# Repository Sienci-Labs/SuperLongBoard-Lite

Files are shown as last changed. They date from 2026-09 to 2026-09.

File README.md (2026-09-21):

# SuperLongBoard Lite

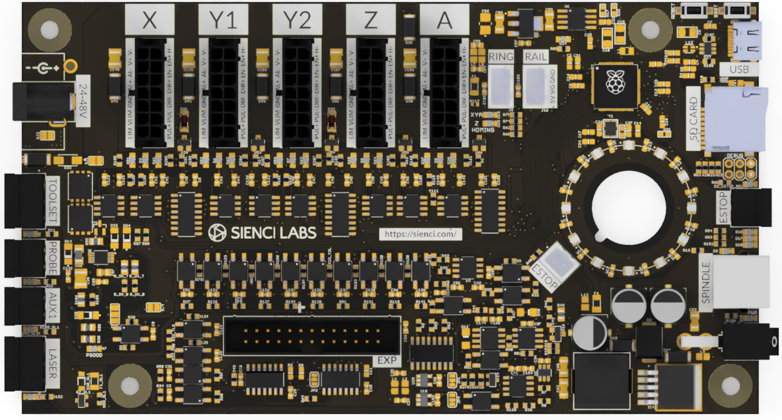
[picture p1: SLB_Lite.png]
SuperLongBoard Lite


The **SuperLongBoard Lite (SLB-Lite)** is Sienci Labs’ 24V CNC controller developed for the LongMill MK3, and other similar machines.

## Key Features

* grblHAL-based firmware
* Four-axis motion control
* Closed-loop stepper motor support
* USB connectivity
* SD card support
* Spindle/router and laser control
* Tool-length sensor support
* Auto-squaring
* Expansion interface
* UF2 firmware updates

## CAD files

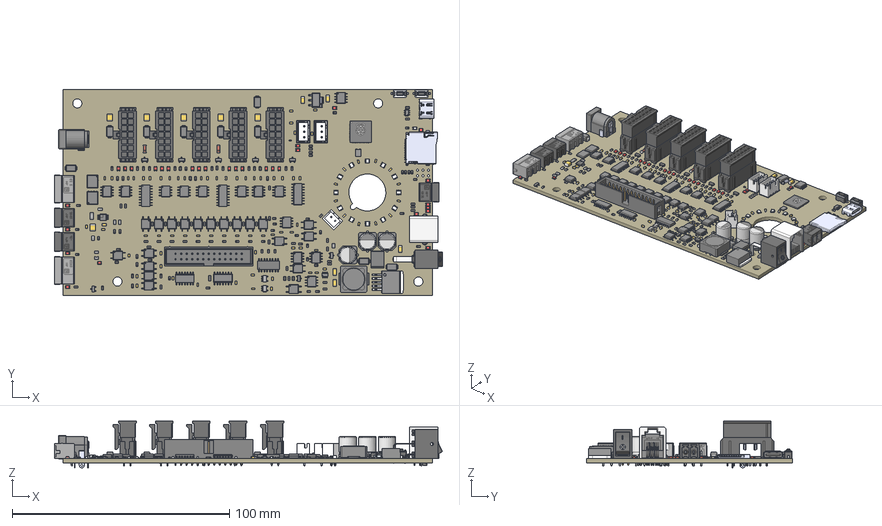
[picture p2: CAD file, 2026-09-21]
CAD/SuperLongboard-Lite 1.3.0.step
178.6 x 95.0 x 21.6 mm
Board
CAPMP3528X210N
SOT23-5 x 2
SOIC127P600X175-8N x 10
SOIC127P600X175-16N x 2
AMS1117-3.3
JST_B2B-XH-A_(LF)(SN)
SOD123FL
SOT95P240X120-3N x 5
QNMOS_PRPAK5X6_HUA x 2
SOIC-8
FIL_DLW21HN900SQ2L
OPTO_EL357N-G x 20
DIO_LL4148 x 4
MUB10A
SOT95P237X125-3N
SOT23
DIOM4325X250N
SOT95P280X145-6N
SOIC127P599X175-8N
USB-C-16P
SMT-JUMPER_3_1-NC_TRACE_SILK x 2
TACTILE_SWITCH_SMD_6.0X3.5MM x 2
MINIMELF x 2
LL-34 x 2
FB805 x 6
SJ x 3
0603-NO x 25
SOIC8_208MIL
SOT-23 x 2
1206L x 3
C0603K x 26
C0603 x 48
C0805
C1206 x 5
C1210 x 6
R0402
R0603 x 109
R1206
TF-PULL
QFN80
SMT-JUMPER_3_1-NC_TRACE_SILK (1)
MC1.5/2-G-3.81 x 3
PHOENIX_1803280 x 2
SOT95P280X145-6N (1)
SOIC127P600X175-14N
KH-PCB-6P6C
SOIC-16
KCD11-BL
JST_B3B-XH-A(LF)(SN) x 2
Components
CUI_DEVICES_MSD-1-A
B2B-XH-A(LF)(SN)
SOLID(5)^RJ11-TH_DS1133-S60BPX_RJ1_RJ11-TH_DS1133-S60BPX_PCB(2)_RJ11- TH_DS1133-S60BPX_PCB_1
Pin2
Pin1
Switch
Switch_IO_Surface
BodyPin1 x 2
DX07S016JA1R1500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

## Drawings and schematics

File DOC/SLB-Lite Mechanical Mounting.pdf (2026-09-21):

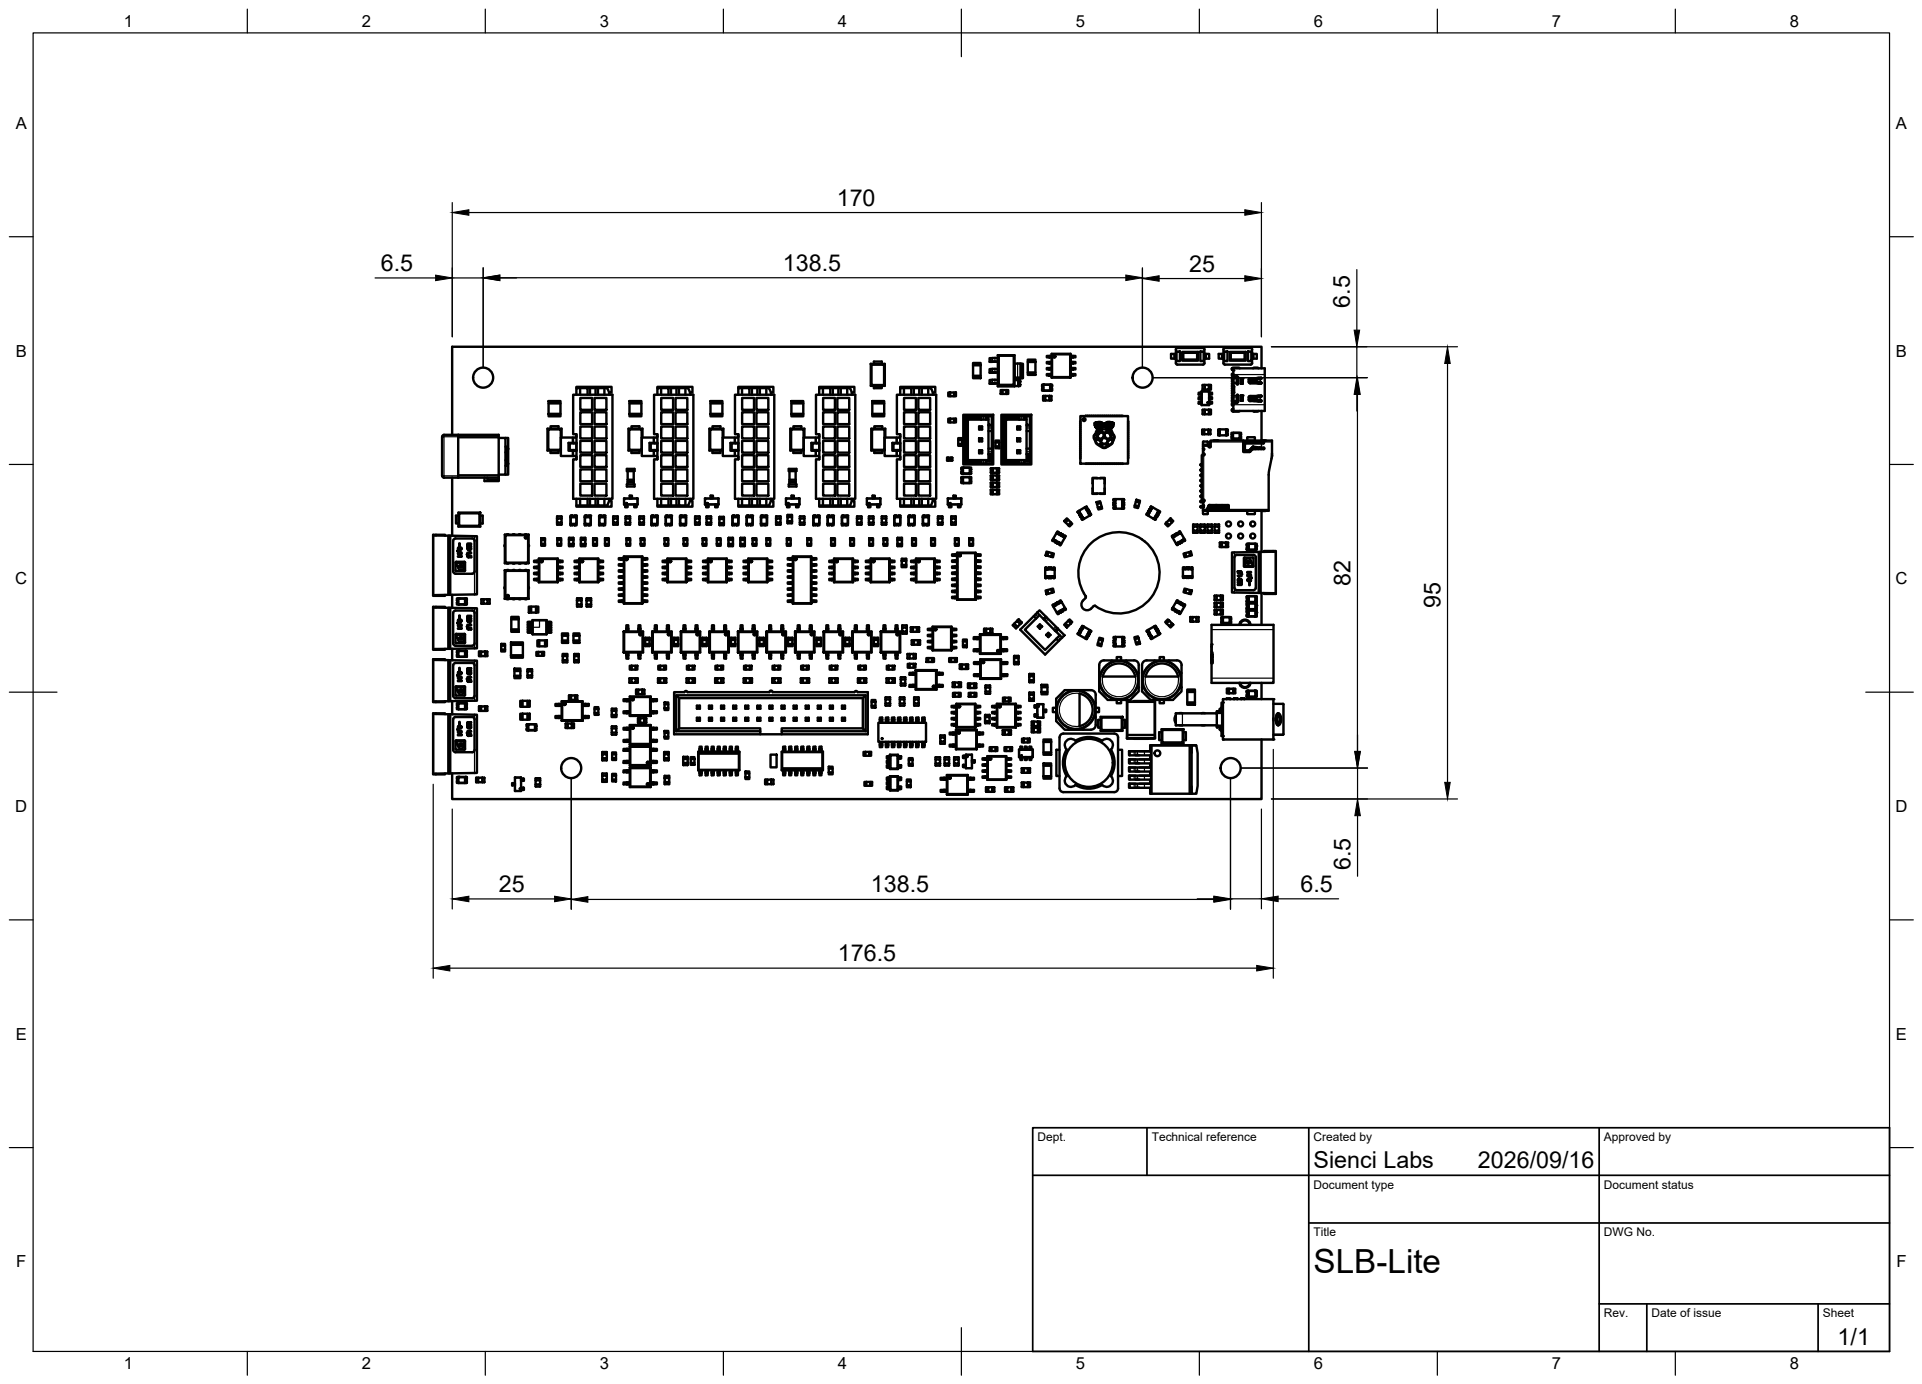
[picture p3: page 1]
Dept.; Technical reference; Created by; Approved by; Document type; Document status; Title; DWG No.; Rev.; Date of issue; Sheet; Sienci Labs

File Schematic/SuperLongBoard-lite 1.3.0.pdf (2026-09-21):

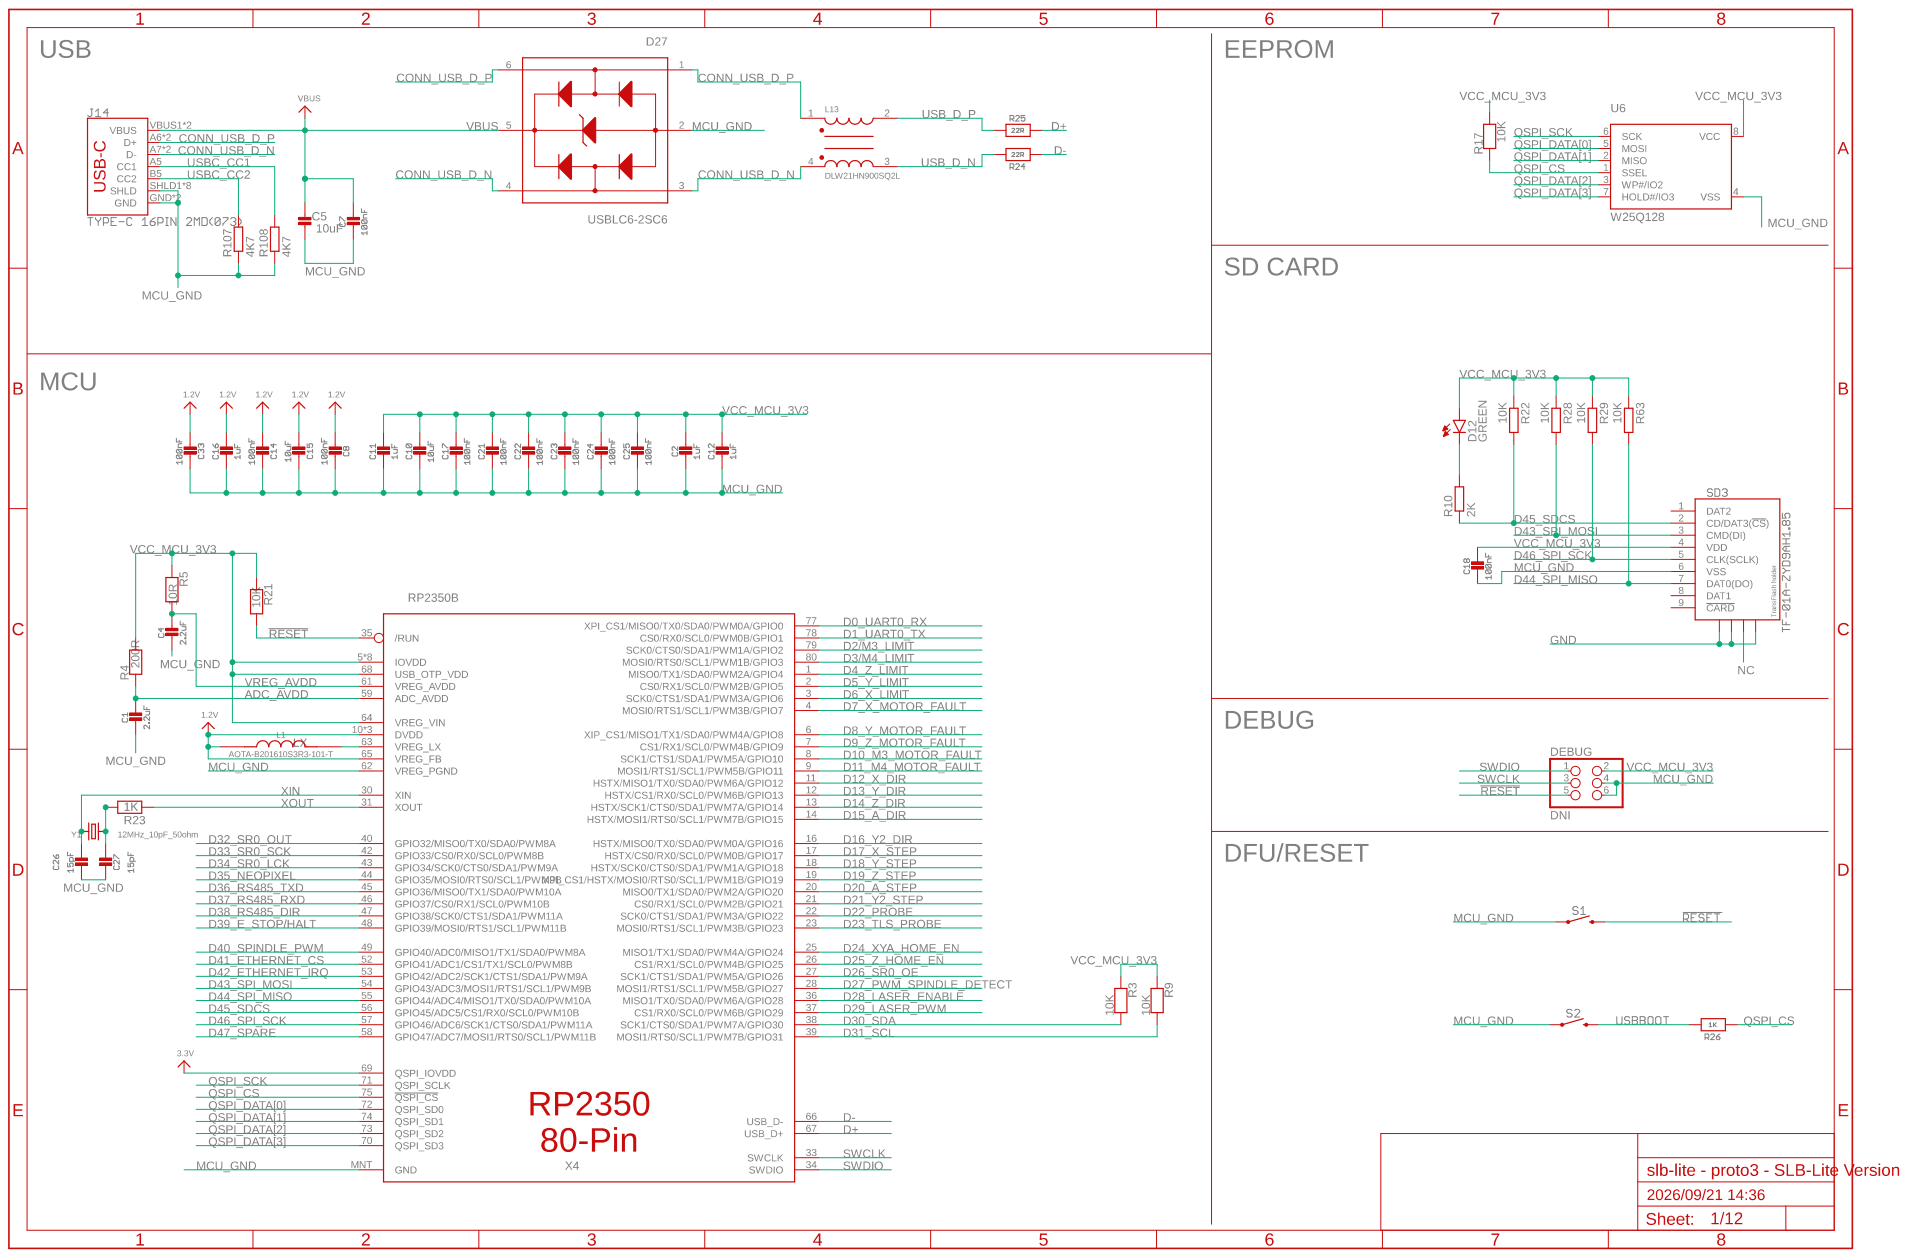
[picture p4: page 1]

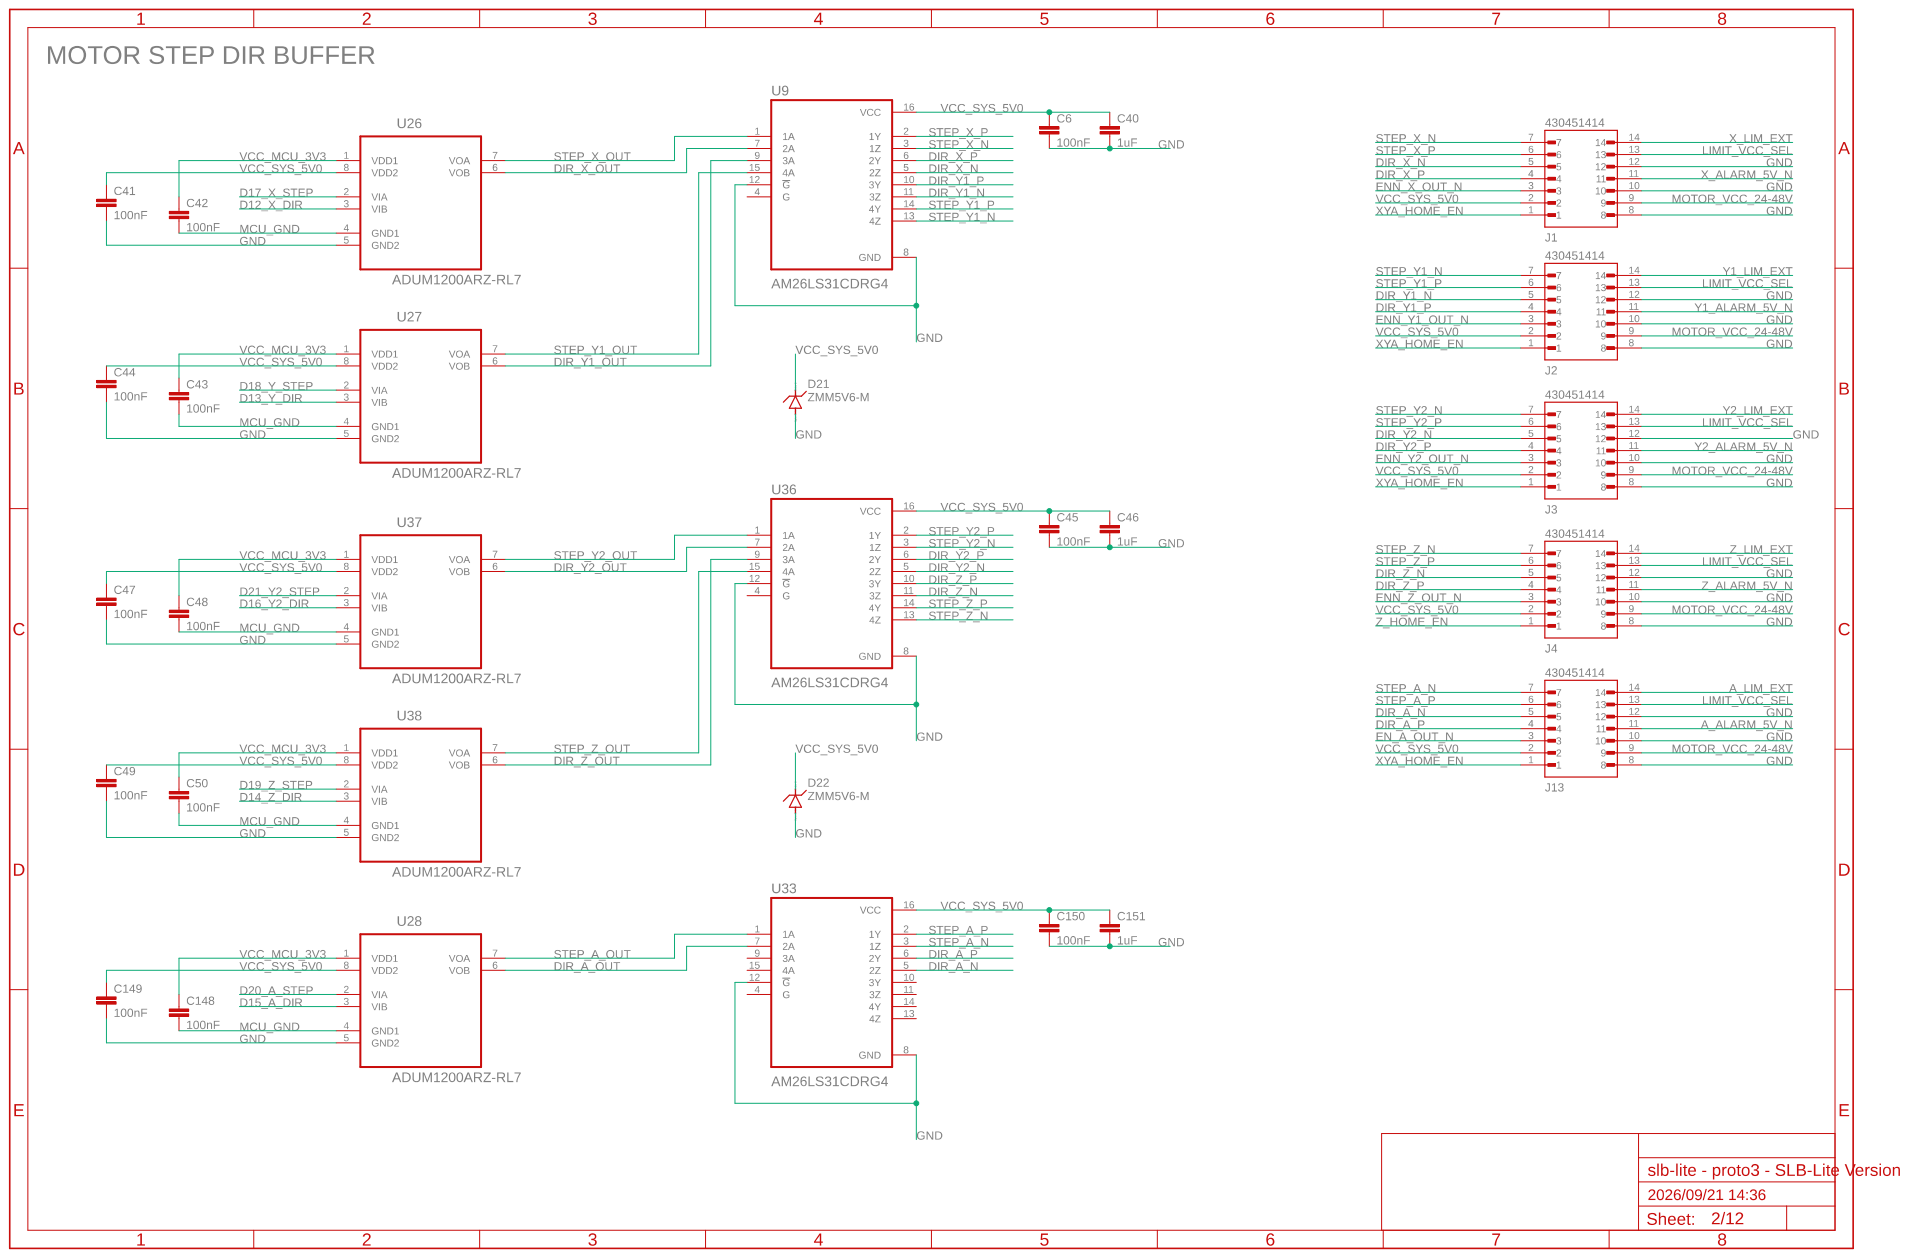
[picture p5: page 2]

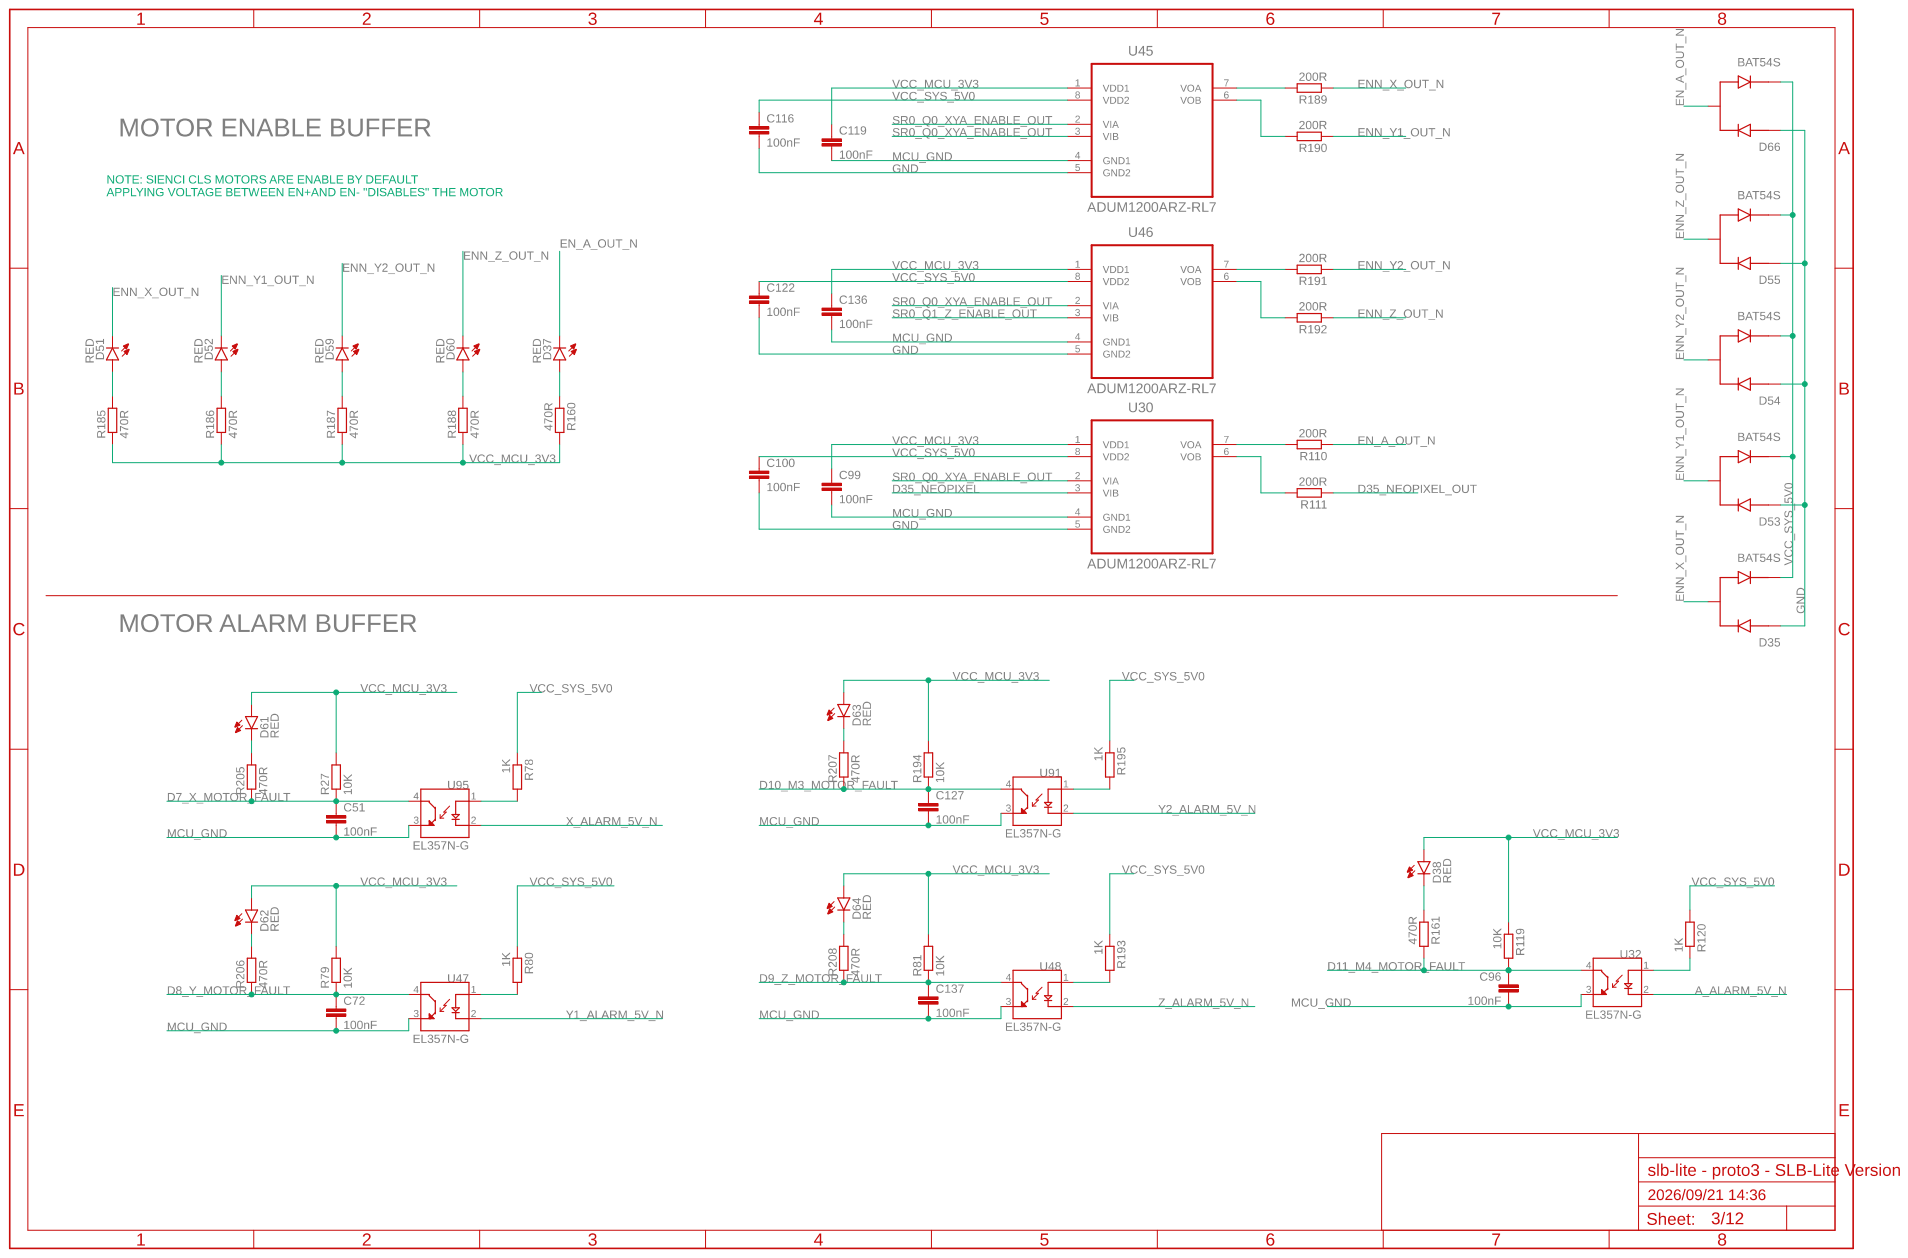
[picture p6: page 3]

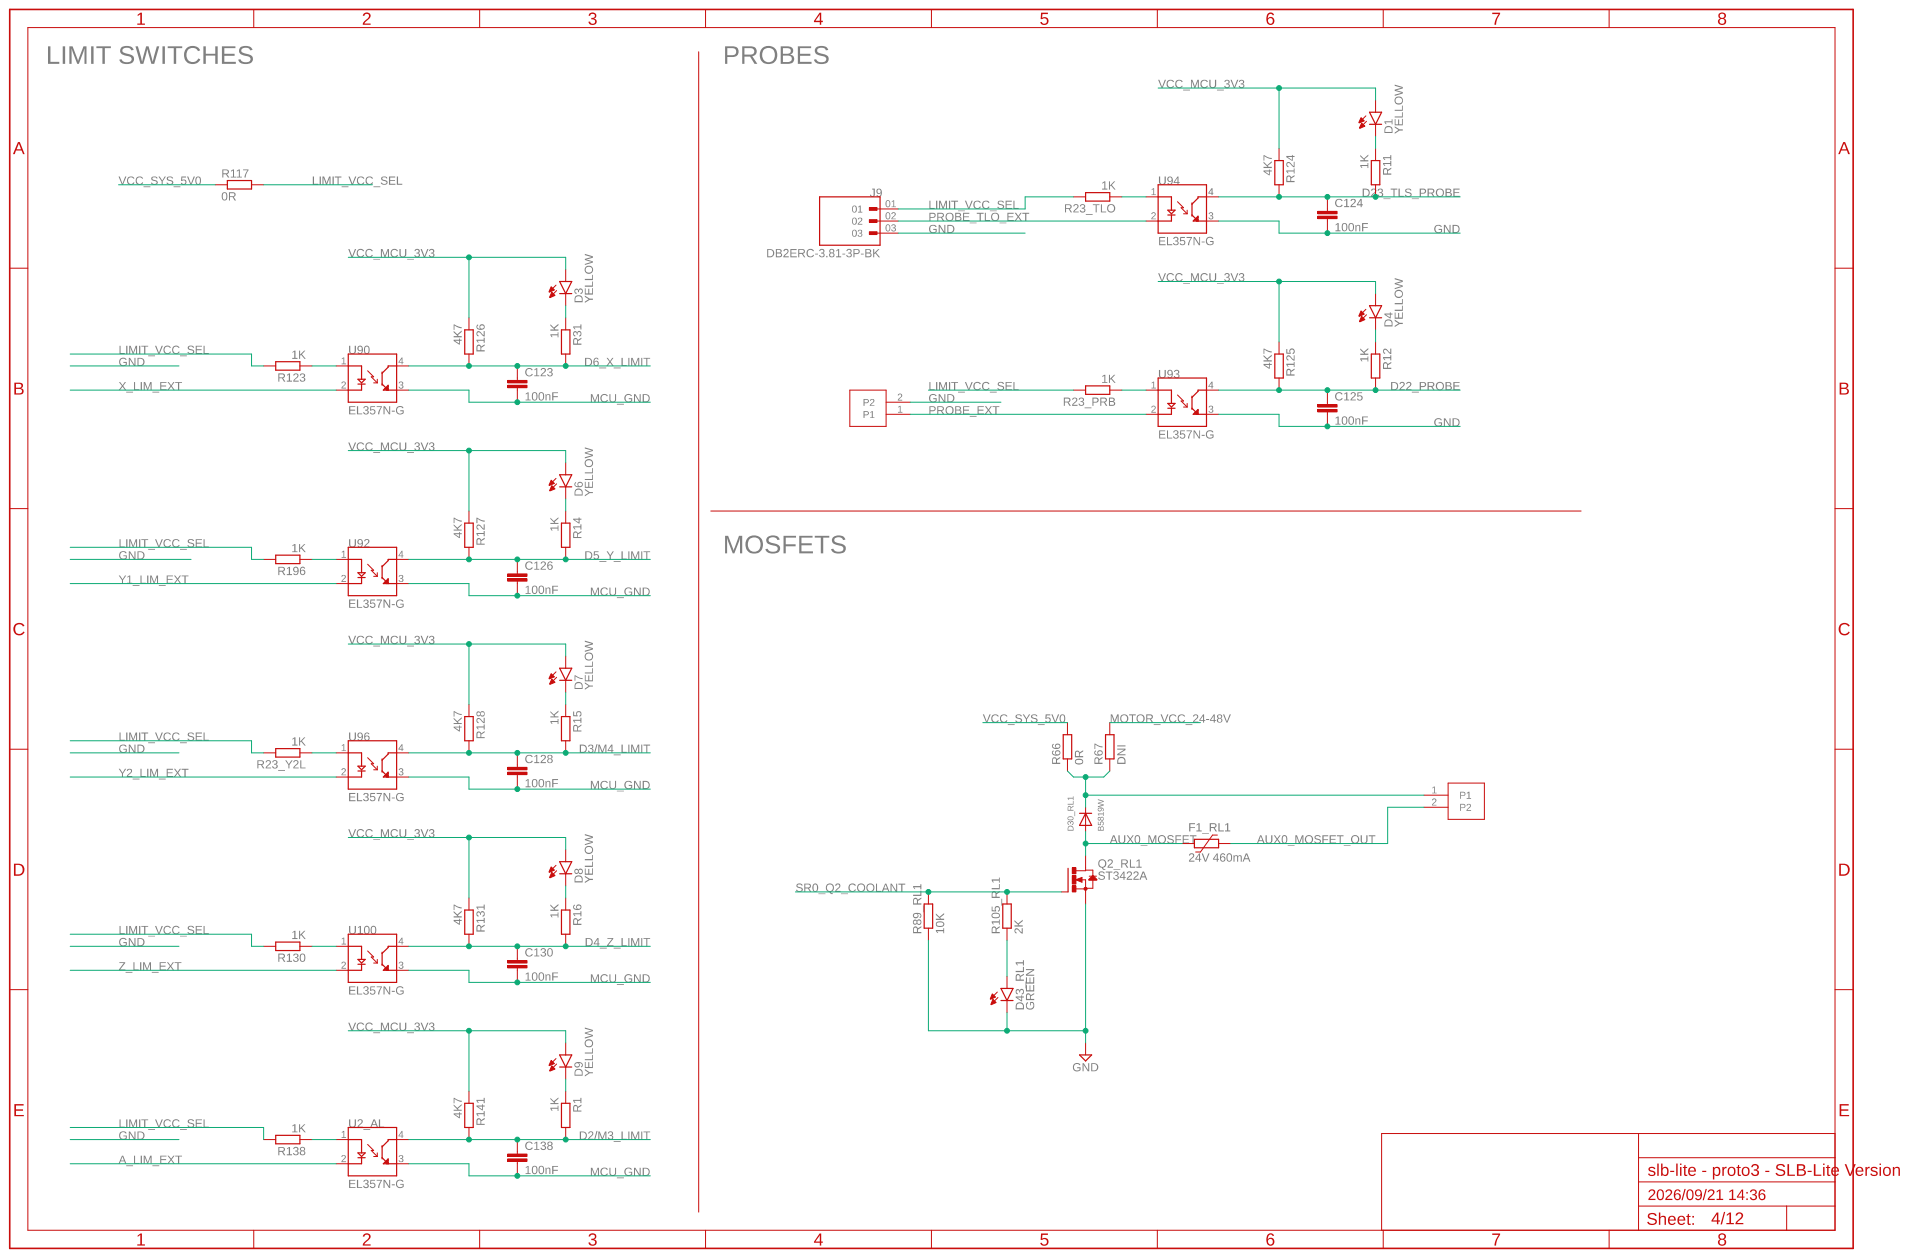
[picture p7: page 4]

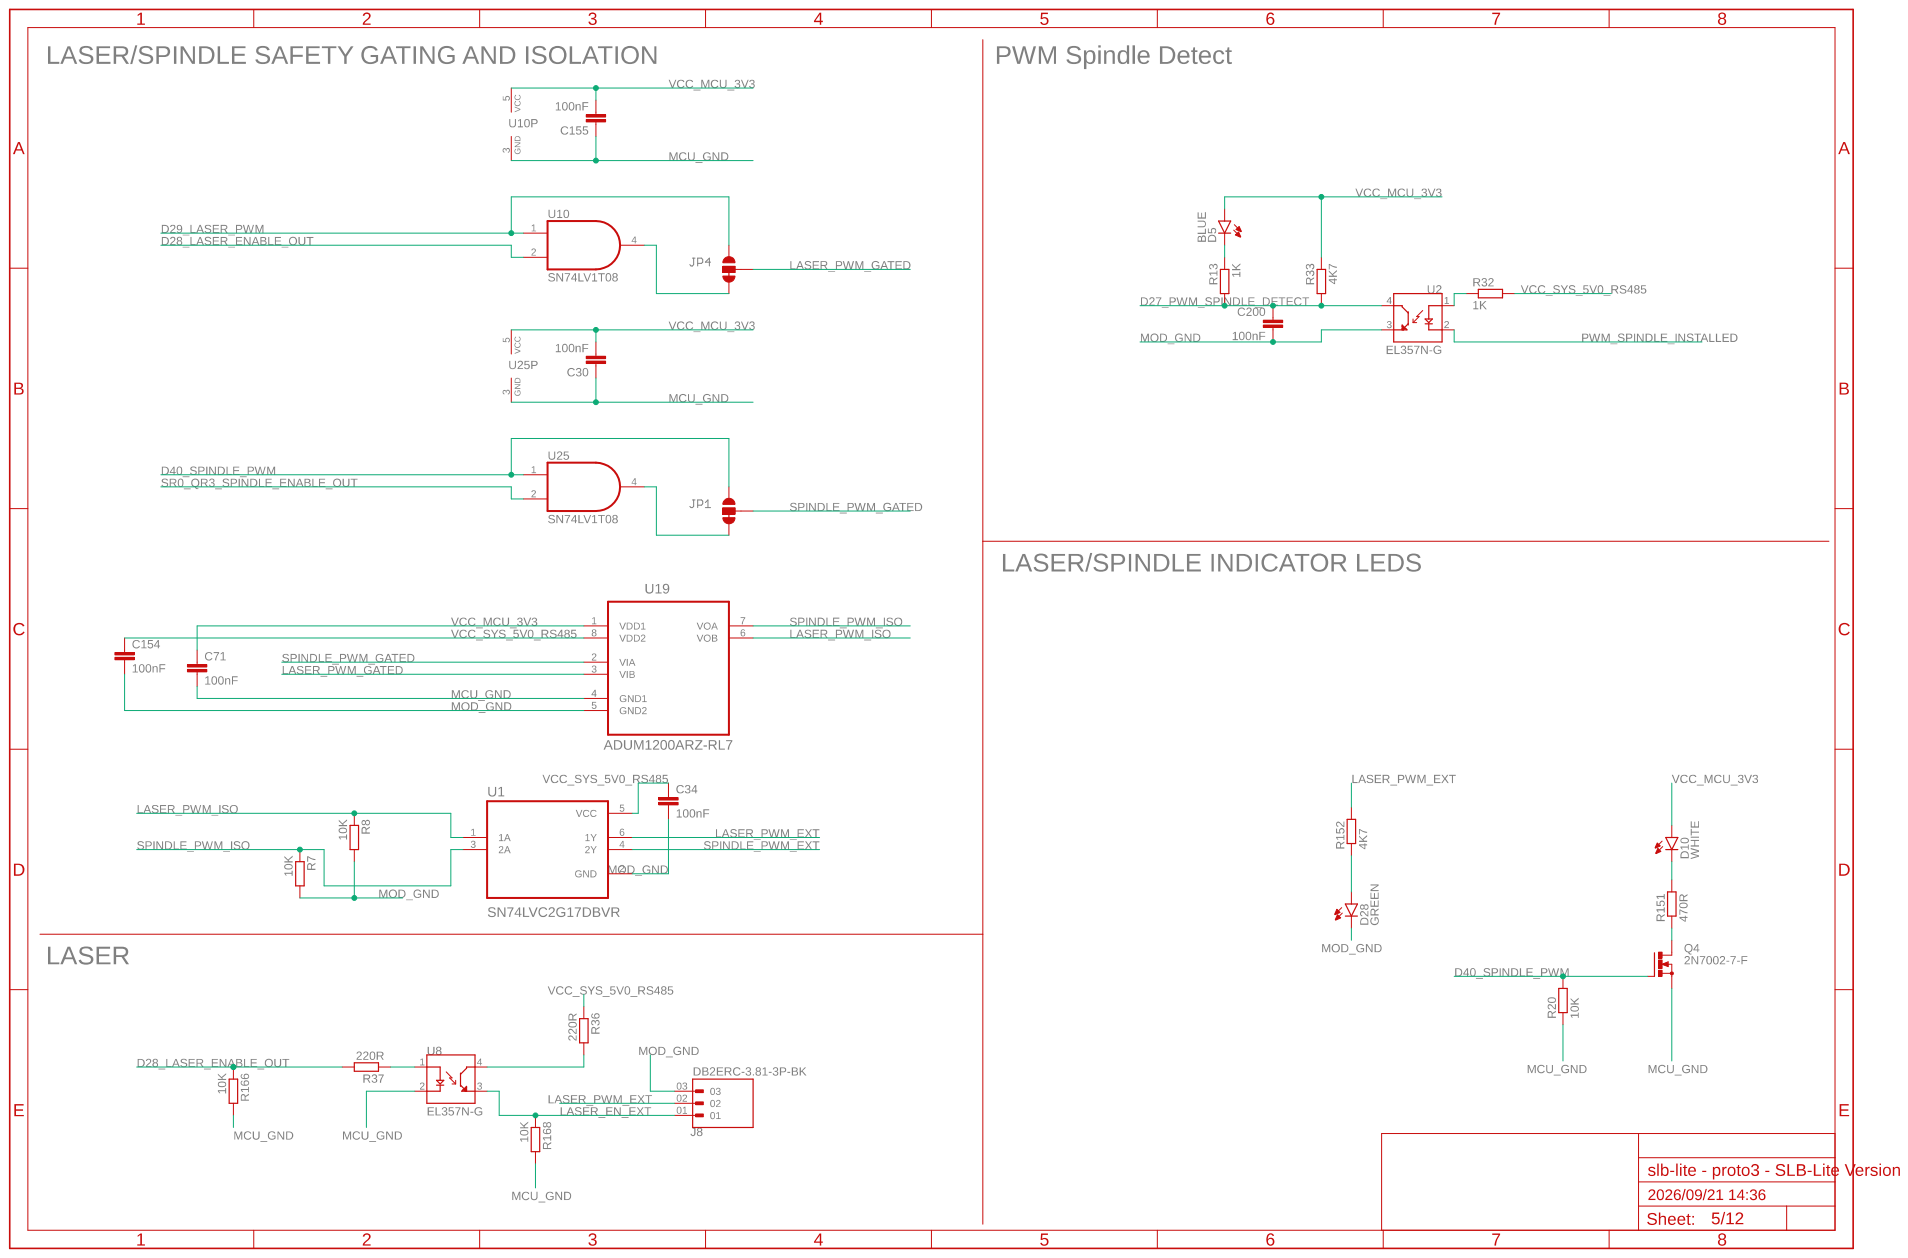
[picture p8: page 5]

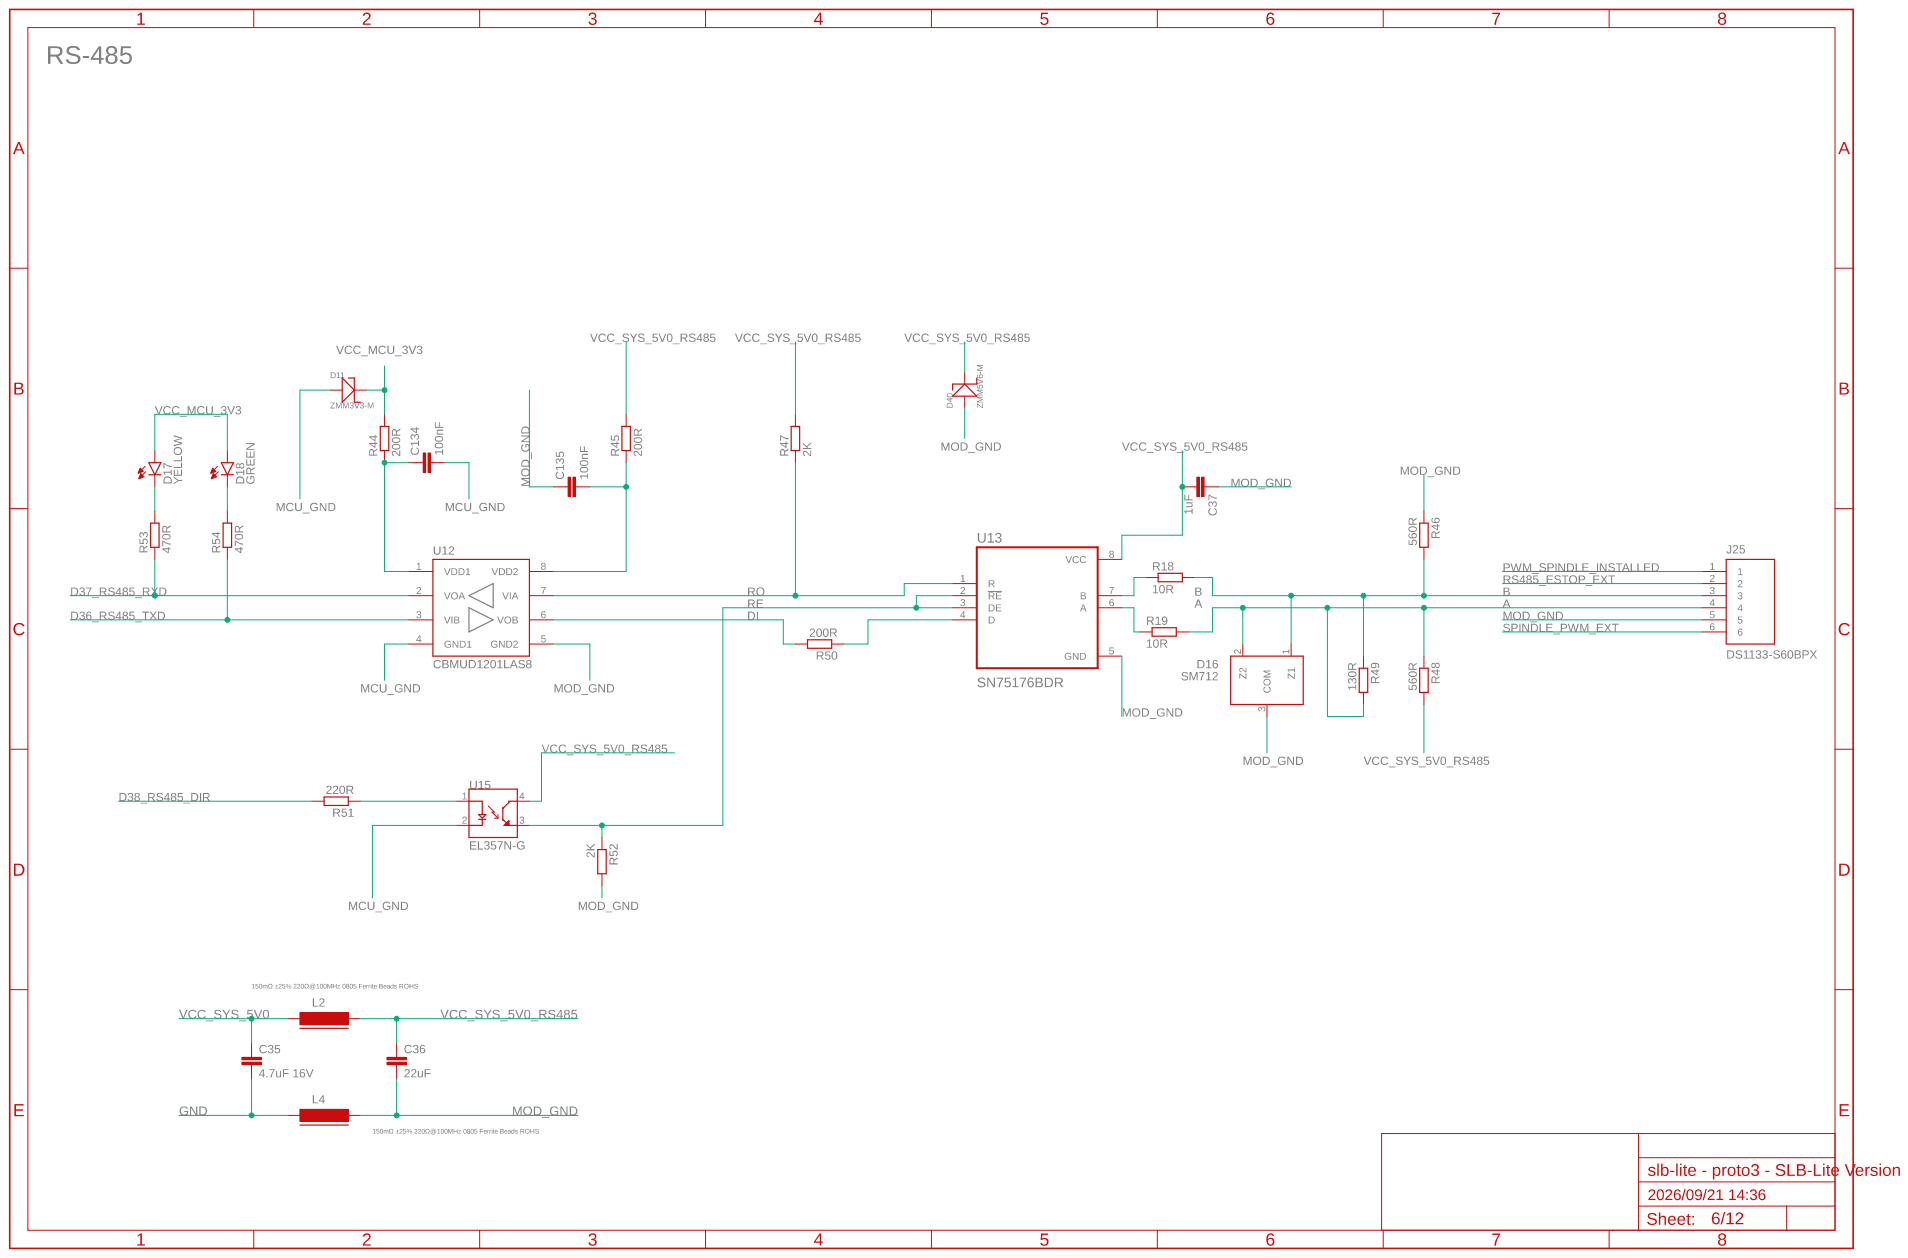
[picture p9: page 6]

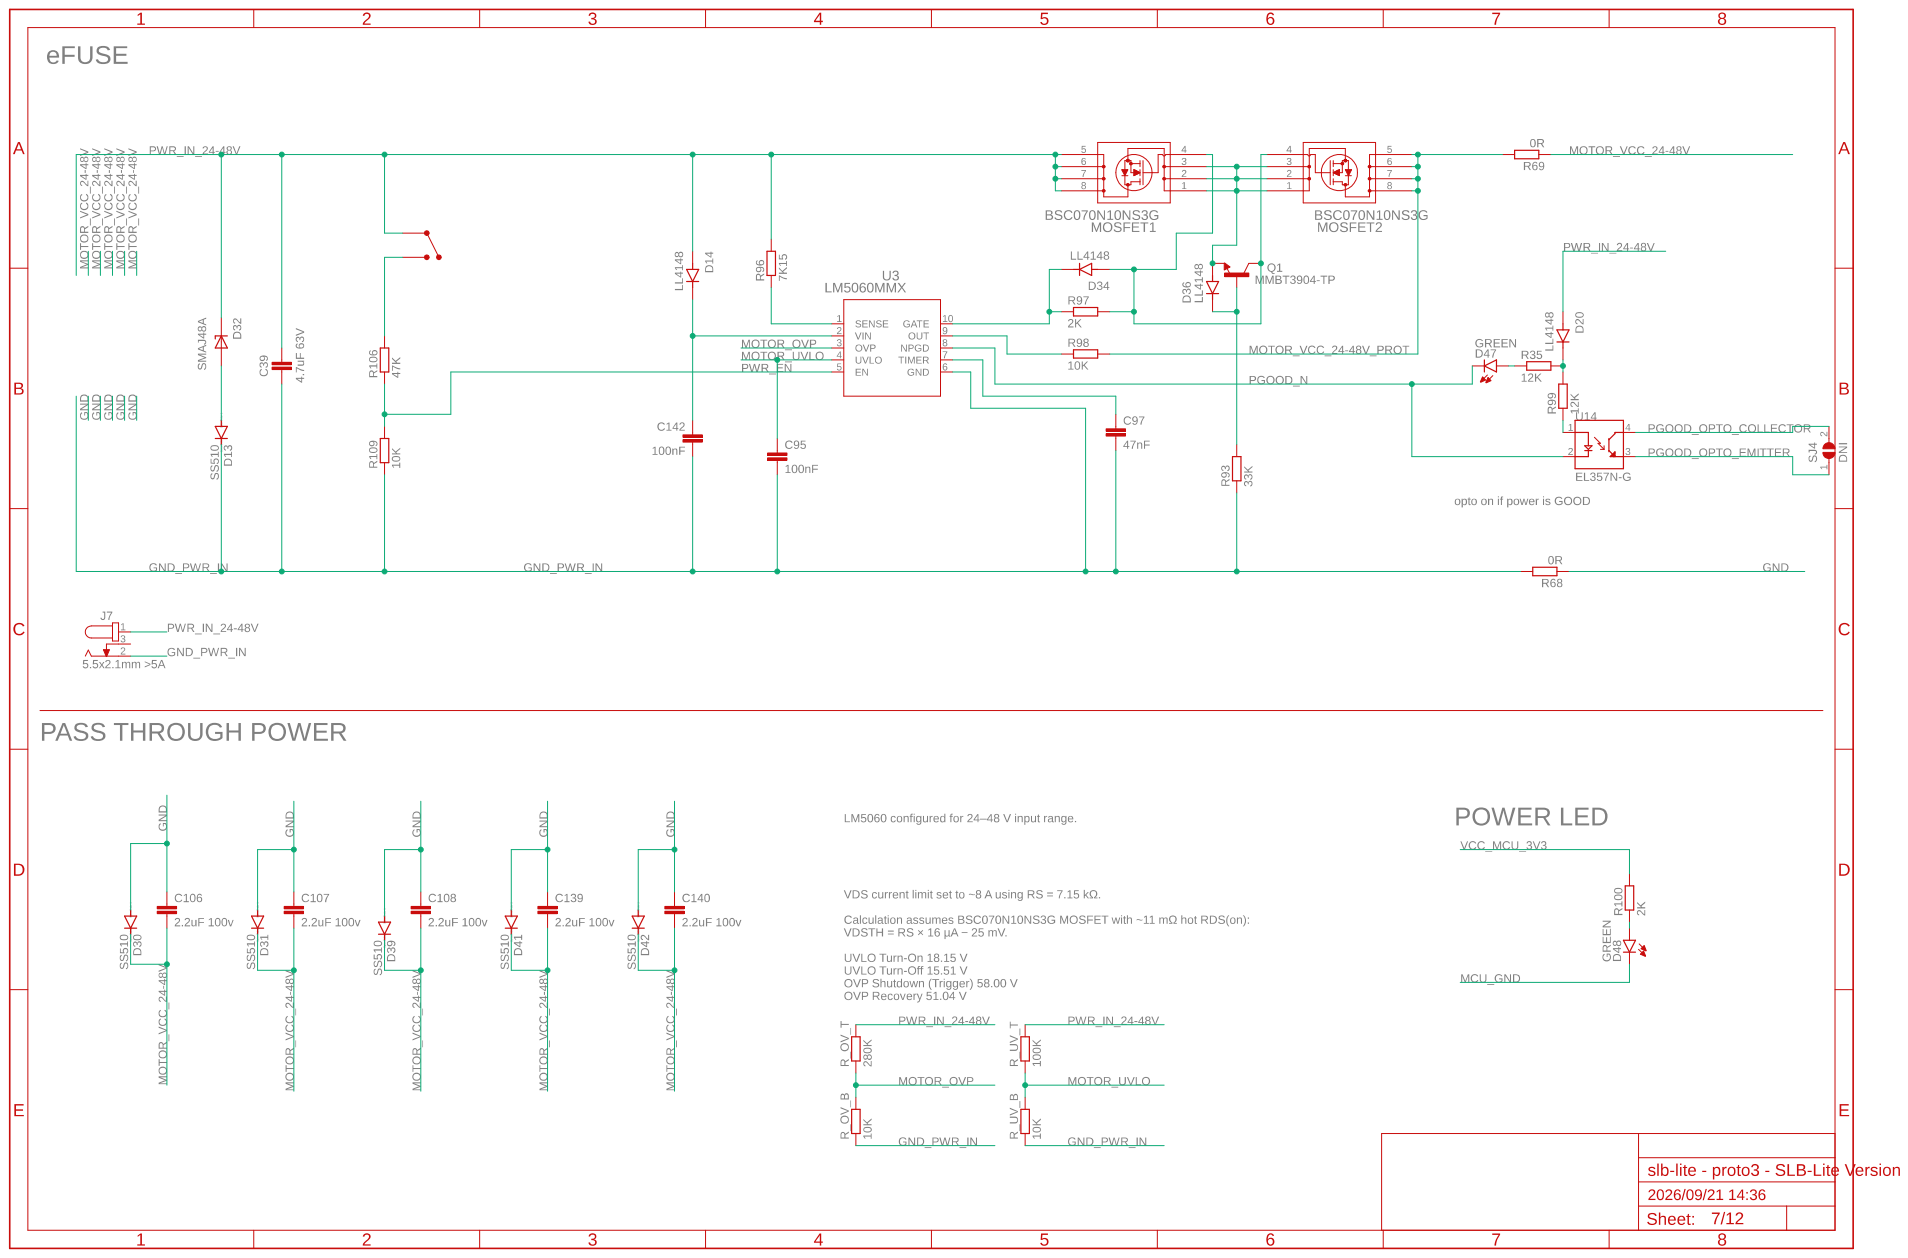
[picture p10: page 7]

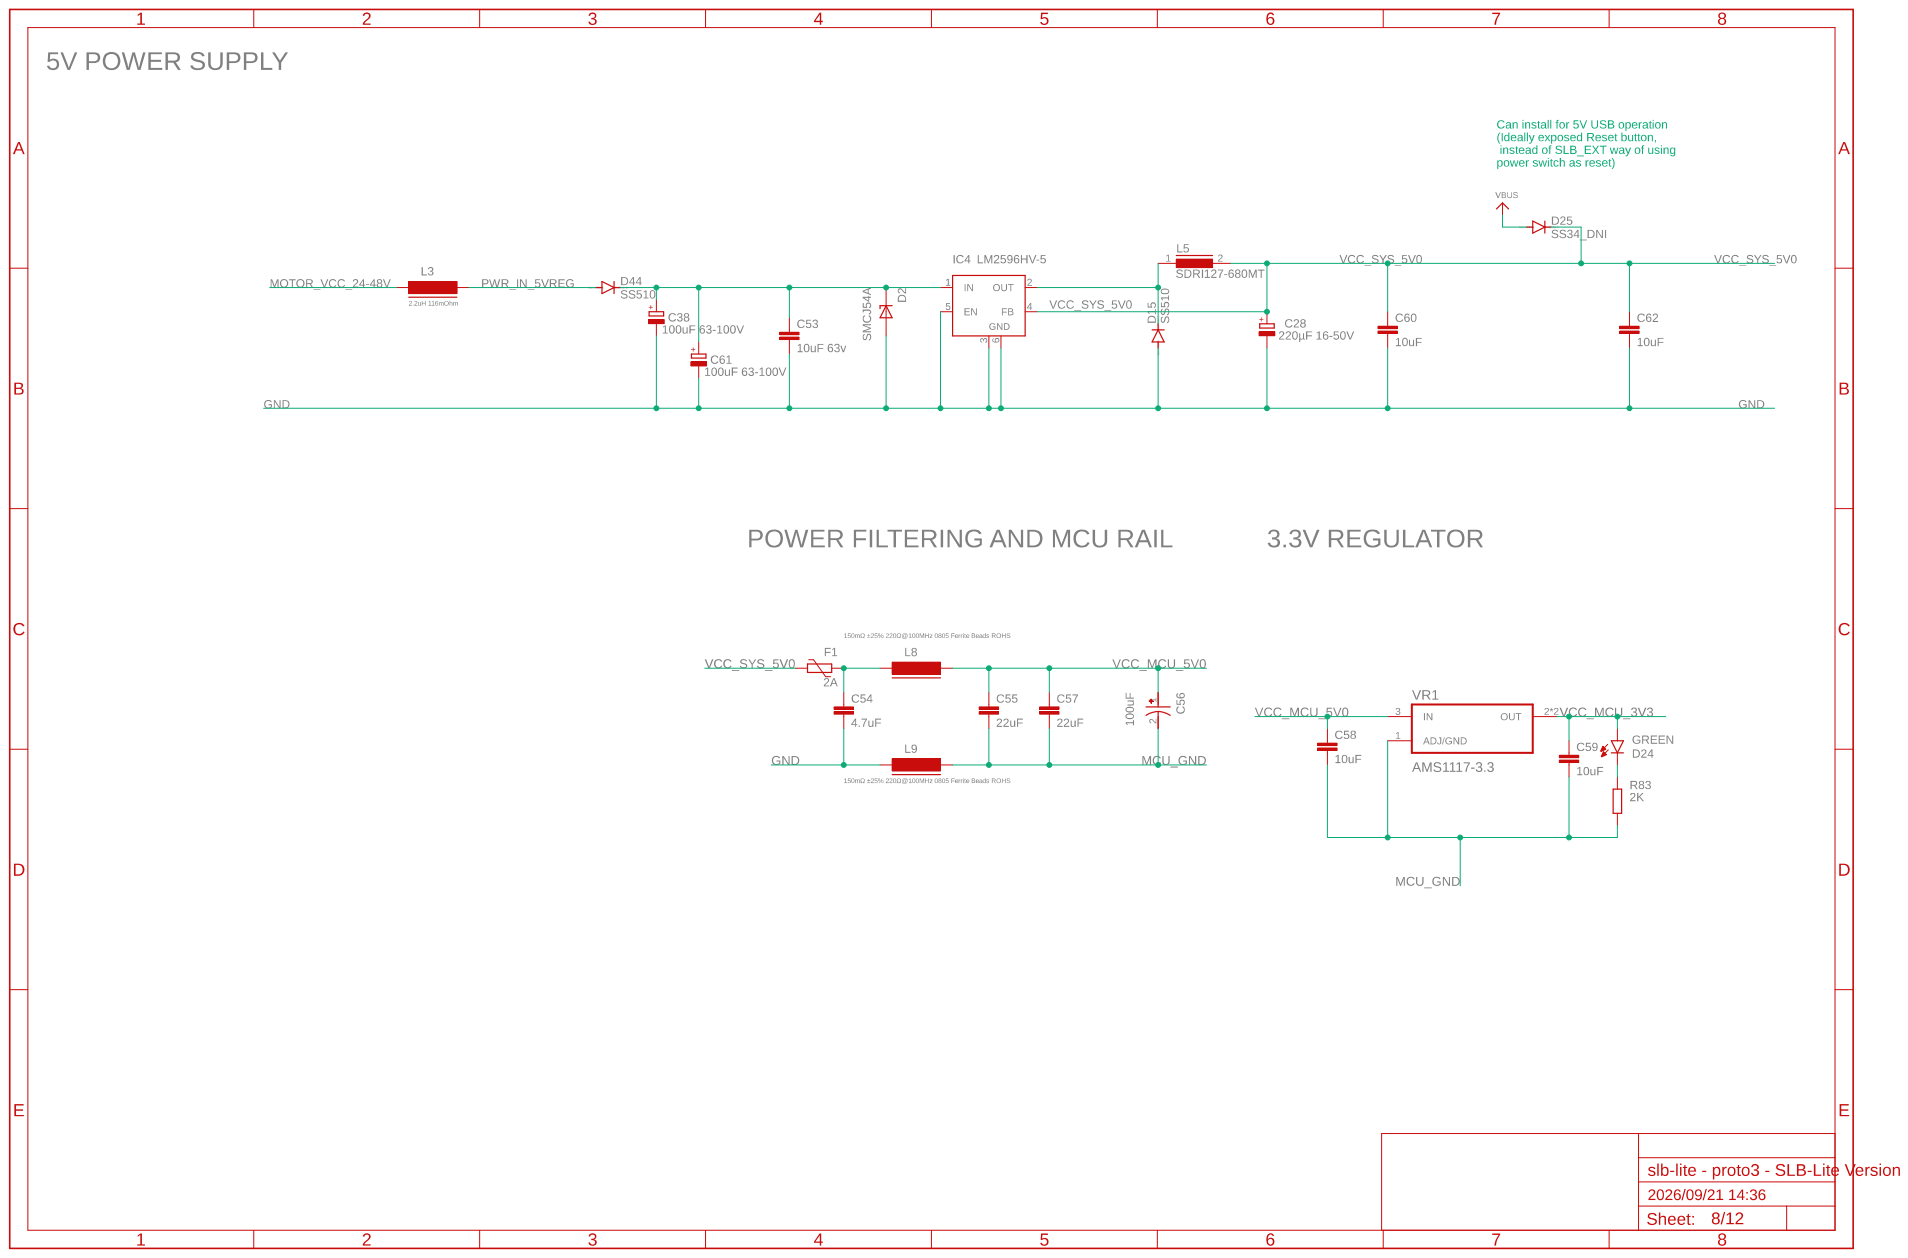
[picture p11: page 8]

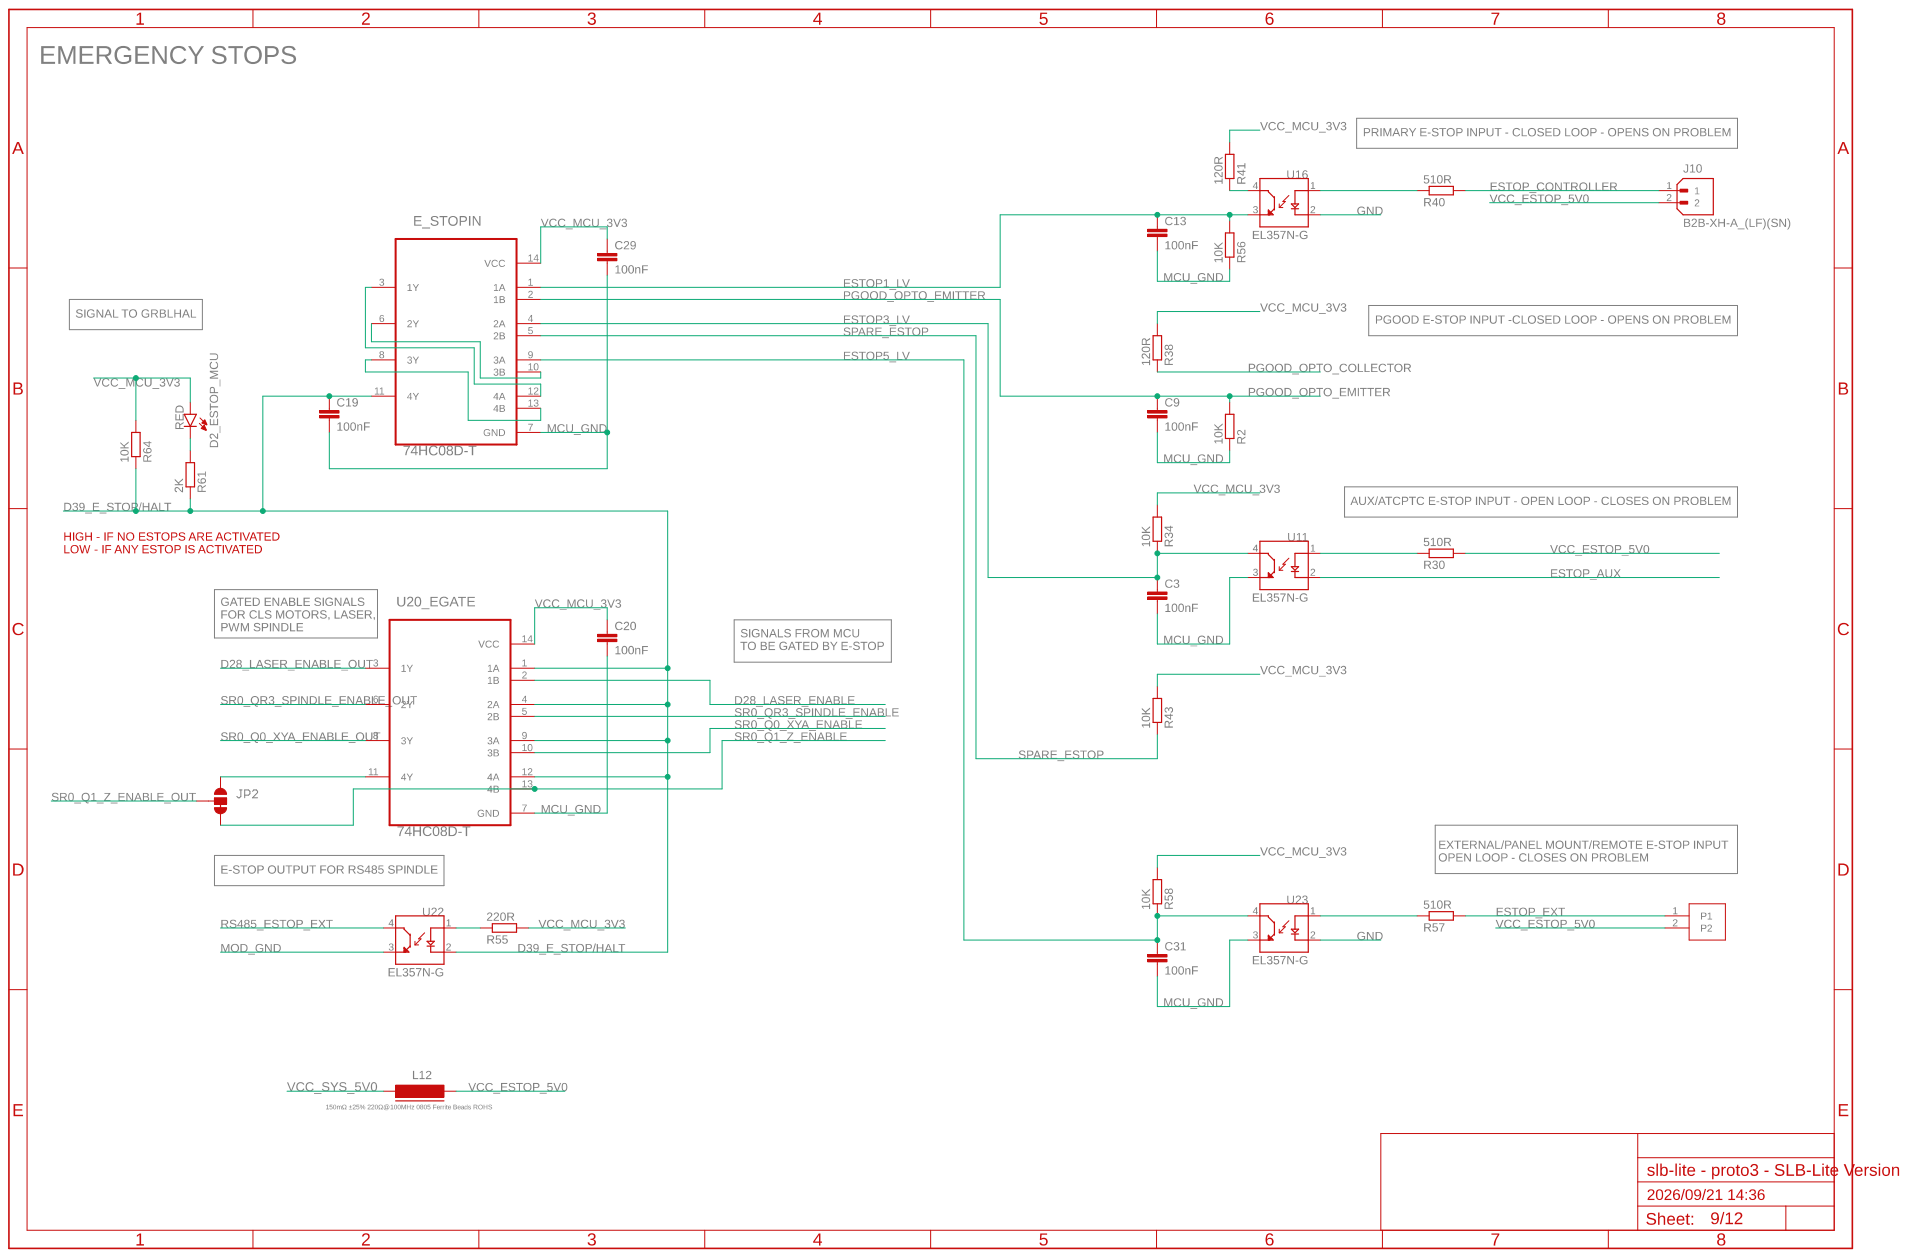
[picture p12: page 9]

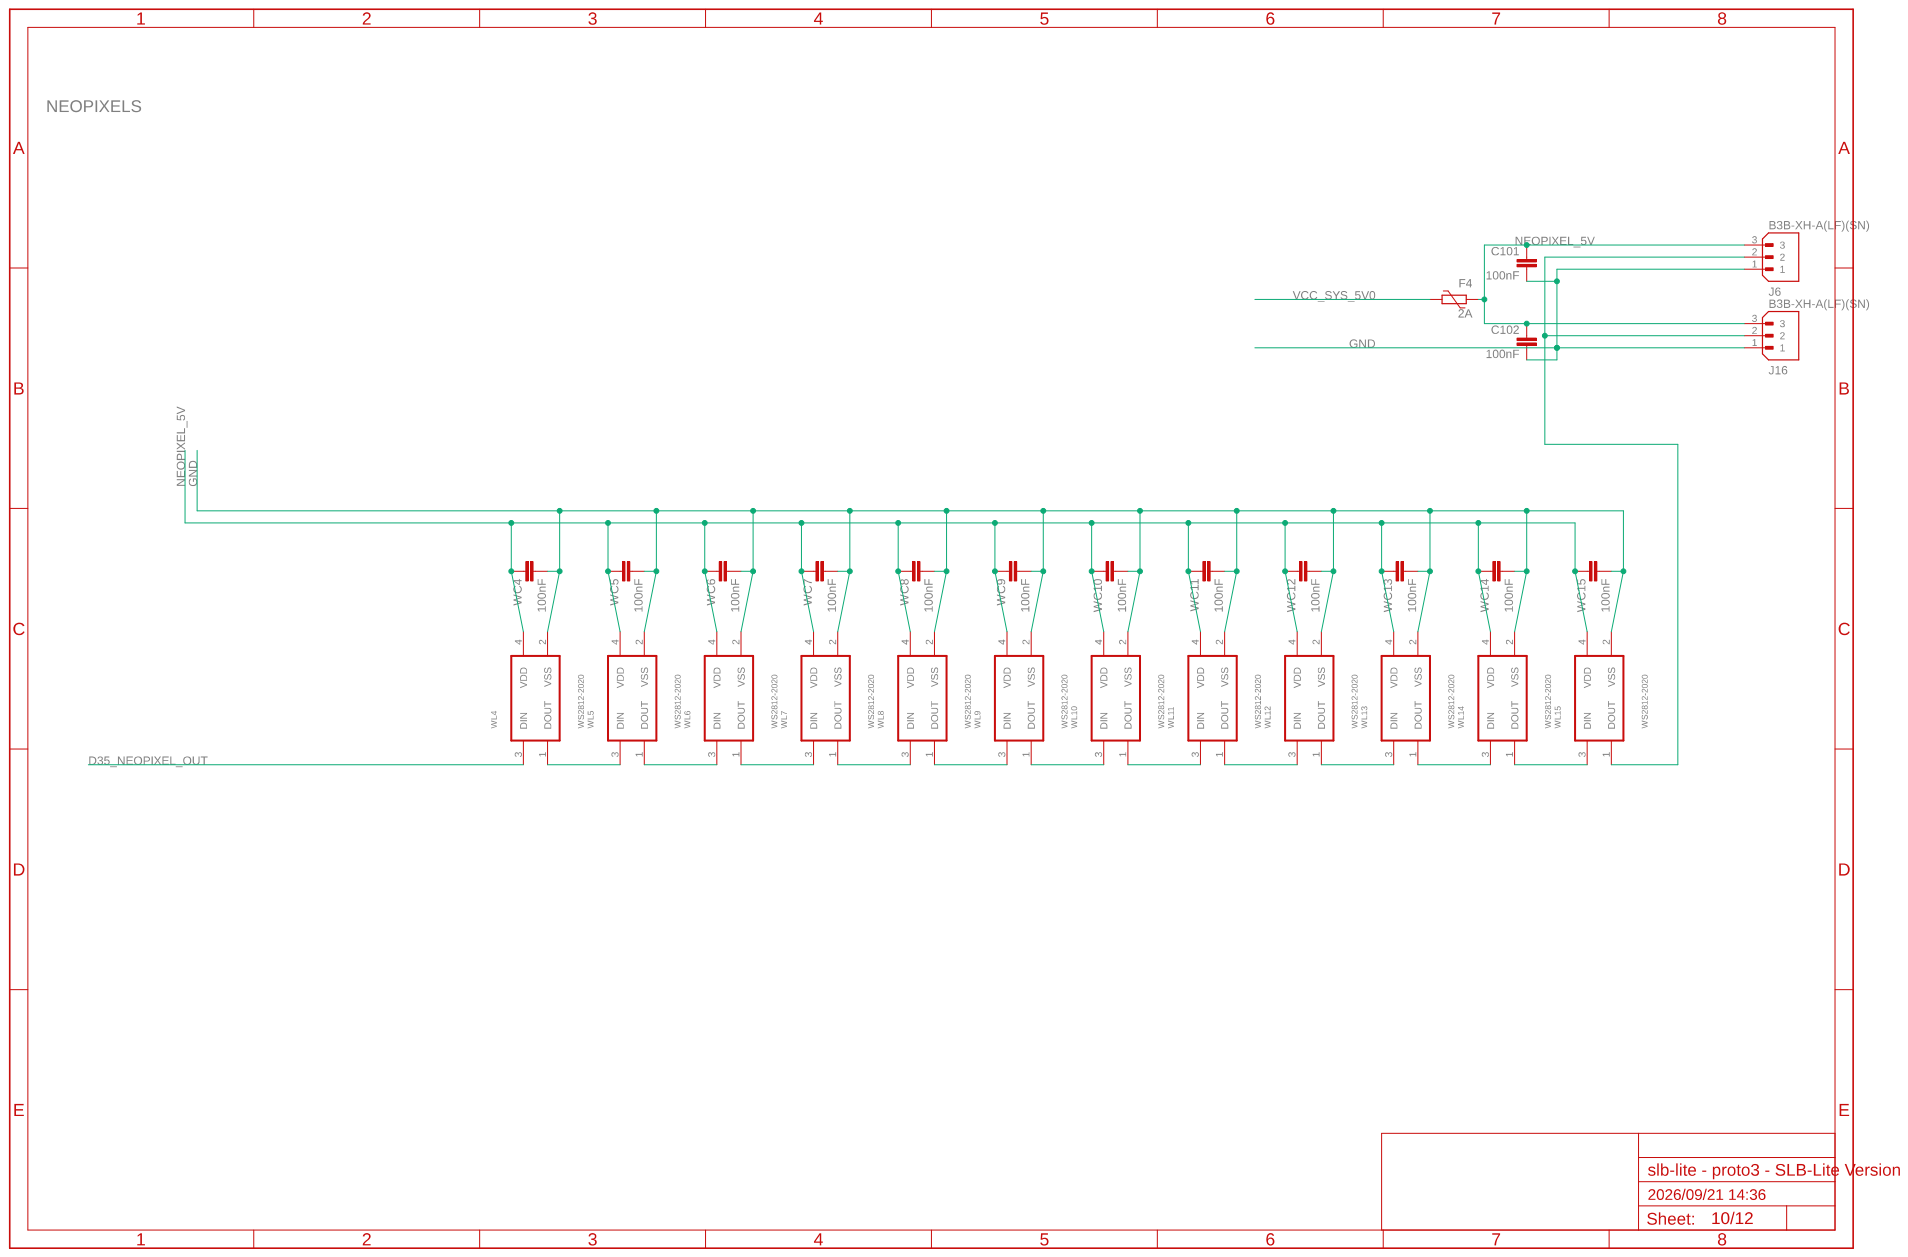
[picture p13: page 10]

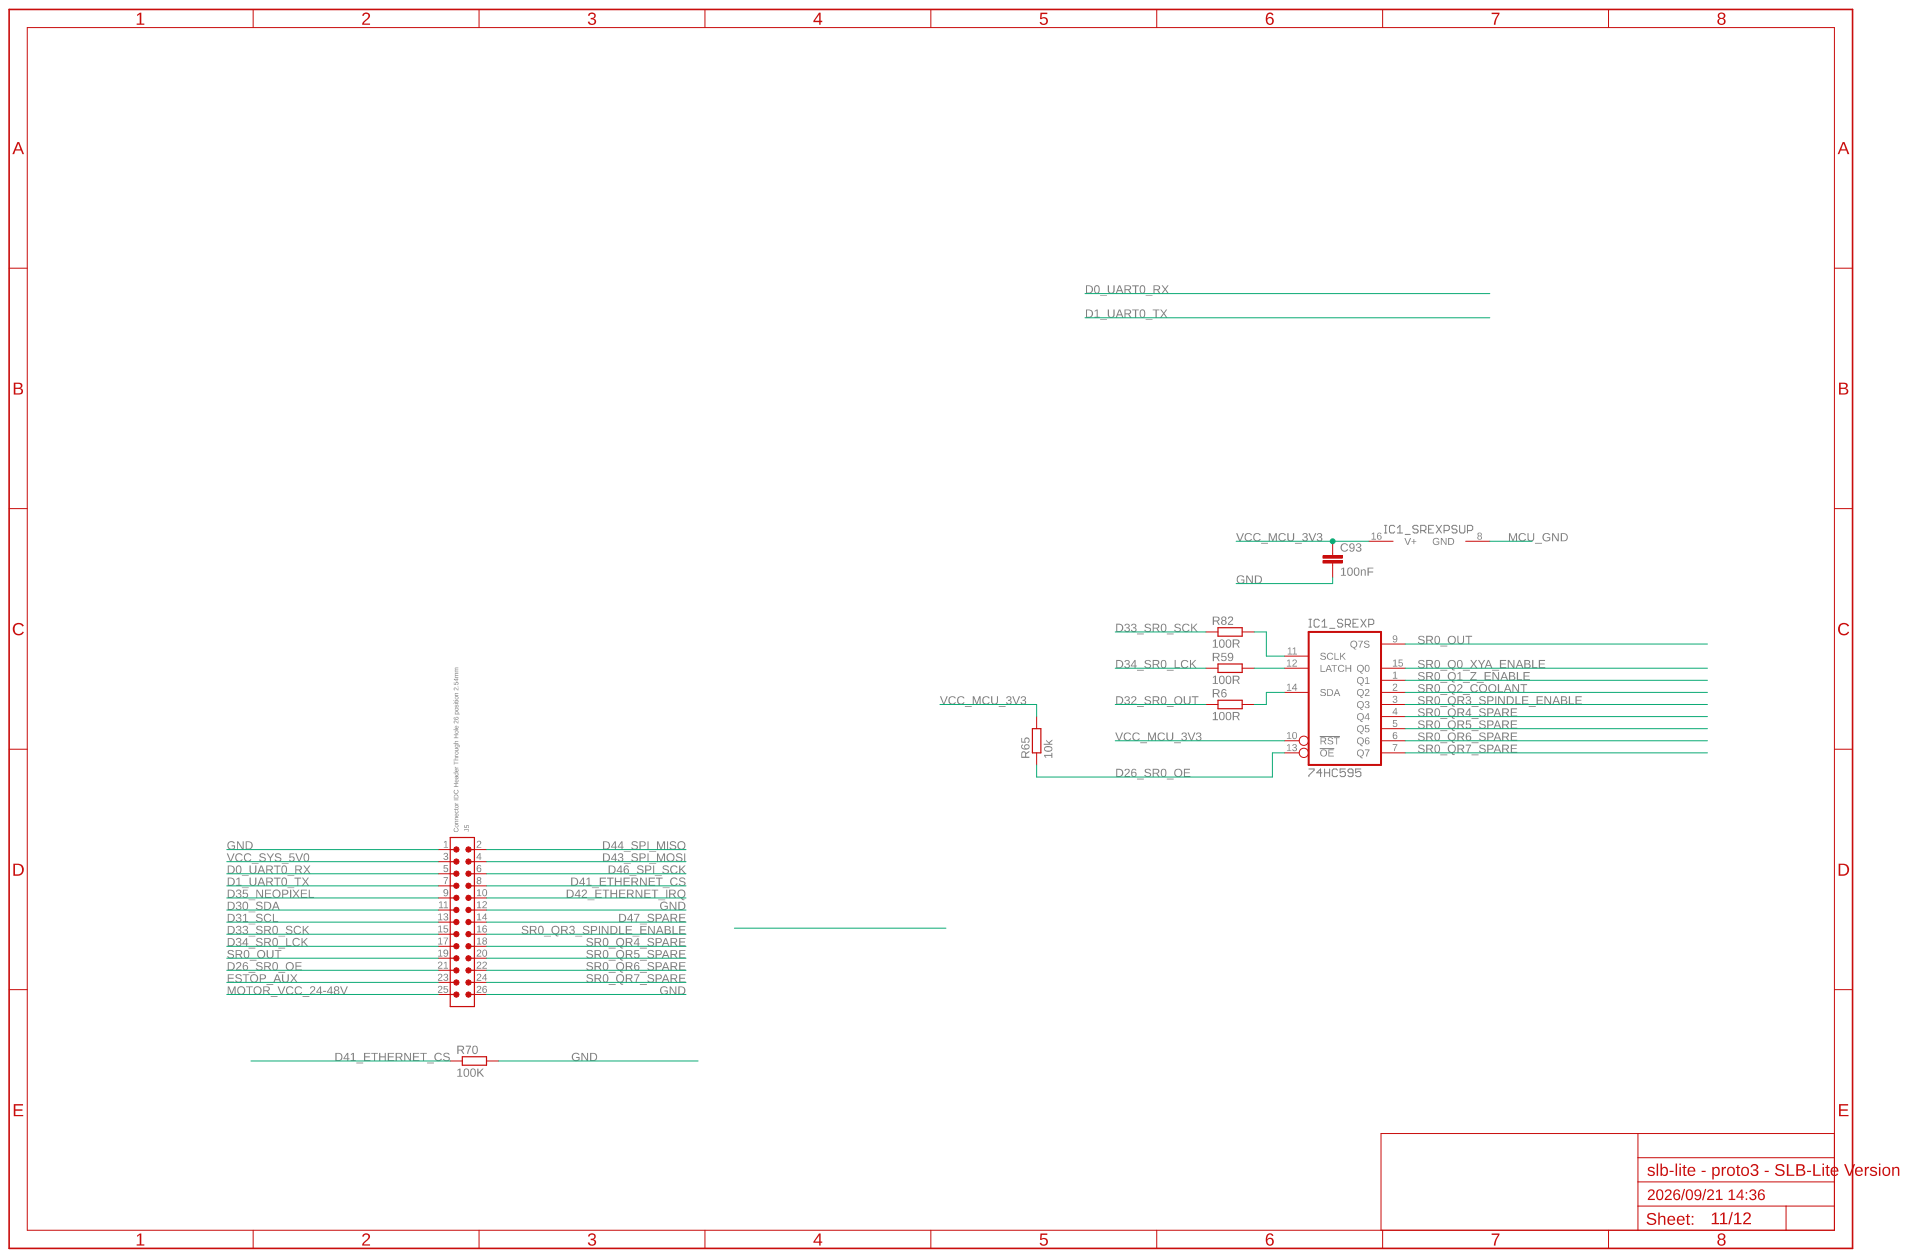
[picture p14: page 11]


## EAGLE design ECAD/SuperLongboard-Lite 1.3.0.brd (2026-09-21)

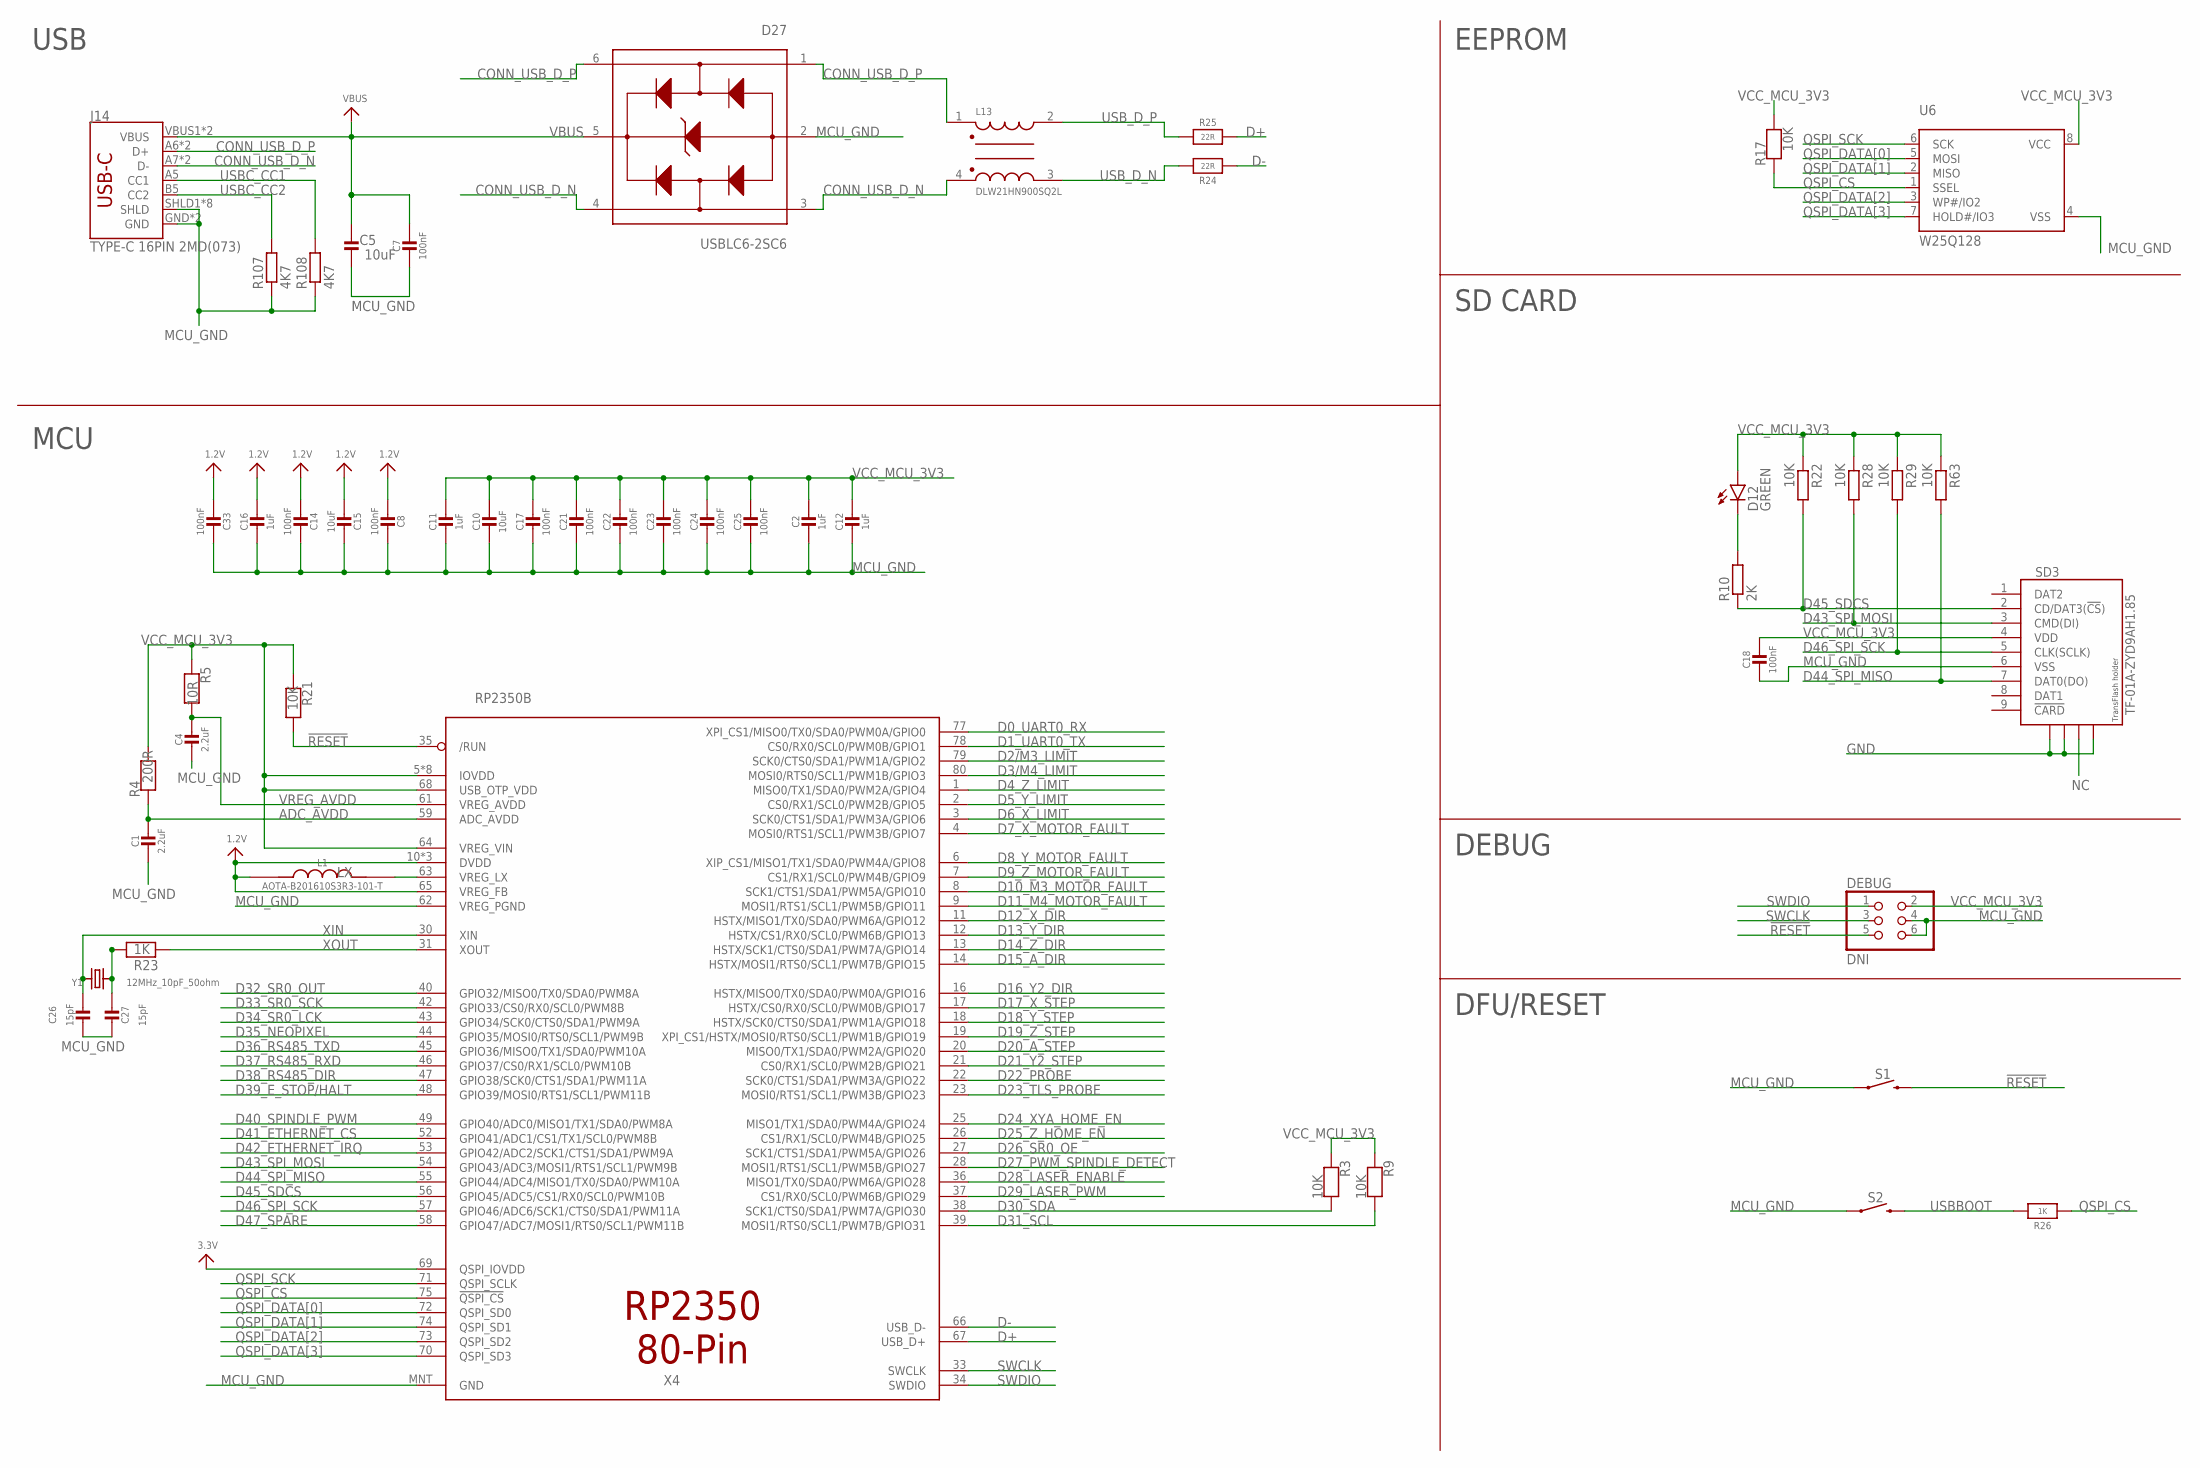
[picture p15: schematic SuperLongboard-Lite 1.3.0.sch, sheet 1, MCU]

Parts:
C1, C4: 2.2uF; 0603-NO
C2, C11, C12, C16: 1uF; 0603-NO
C5, C10, C15: 10uF; _1206
C7, C8, C14, C17, C18, C21, C22, C23, C24, C25, C33: 100nF; 0603-NO
C26, C27: 15pF; 0603-NO
D12: GREEN; CHIP-LED0805
D27: USBLC6-2SC6; SOT95P280X145-6N
DEBUG: DNI; 2X03
J14: TYPE-C 16PIN 2MD(073); USB-C-16P
L1: AOTA-B201610S3R3-101-T; INDUCTOR-0806; LCSC_PART C42411119
L13: DLW21HN900SQ2L; FIL_DLW21HN900SQ2L
R3, R9: 10K; 0603-NO
R4: 200R; 0603-NO
R5: 10R; 0603-NO
R10: 2K; R0603
R17, R21: 10K; _0603
R22, R28, R29, R63: 10K; R0603
R23, R26: 1K; _0603
R24, R25: 22R; 0603-NO
R107, R108: 4K7; R0603
S1, S2: ZX-QC36-4.3TPWD; TACTILE_SWITCH_SMD_6.0X3.5MM
SD3: TF-01A-ZYD9AH1.85; TF-PULL
U6: W25Q128; SOIC8_208MIL
X4: RP2350B; QFN80
Y1: 12MHz_10pF_50ohm; CRYSTAL_3.2X2.5

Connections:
1.2V: C8.2, C14.2, C15.2, C16.1, C33.2, L1.1, X4.10 (DVDD), X4.32 (DVDD), X4.51 (DVDD), X4.65 (VREG_FB)
!RESET: DEBUG.5, R21.2, S1.2, X4.35 (/RUN)
ADC_AVDD: C1.1, R4.1, X4.59 (ADC_AVDD)
CONN_USB_D_N: D27.3 (I/O2_IN), D27.4 (I/O2_OUT), J14.A7 (D-), J14.B7 (D-), L13.4
CONN_USB_D_P: D27.1 (I/O1_IN), D27.6 (I/O1_OUT), J14.A6 (D+), J14.B6 (D+), L13.1
D0_UART0_RX: X4.77 (XPI_CS1/MISO0/TX0/SDA0/PWM0A/GPIO0); also elsewhere on the board
D1_UART0_TX: X4.78 (CS0/RX0/SCL0/PWM0B/GPIO1); also elsewhere on the board
D2/M3_LIMIT: X4.79 (SCK0/CTS0/SDA1/PWM1A/GPIO2); also elsewhere on the board
D3/M4_LIMIT: X4.80 (MOSI0/RTS0/SCL1/PWM1B/GPIO3); also elsewhere on the board
D4_Z_LIMIT: X4.1 (MISO0/TX1/SDA0/PWM2A/GPIO4); also elsewhere on the board
D5_Y_LIMIT: X4.2 (CS0/RX1/SCL0/PWM2B/GPIO5); also elsewhere on the board
D6_X_LIMIT: X4.3 (SCK0/CTS1/SDA1/PWM3A/GPIO6); also elsewhere on the board
D7_X_MOTOR_FAULT: X4.4 (MOSI0/RTS1/SCL1/PWM3B/GPIO7); also elsewhere on the board
D8_Y_MOTOR_FAULT: X4.6 (XIP_CS1/MISO1/TX1/SDA0/PWM4A/GPIO8); also elsewhere on the board
D9_Z_MOTOR_FAULT: X4.7 (CS1/RX1/SCL0/PWM4B/GPIO9); also elsewhere on the board
D10_M3_MOTOR_FAULT: X4.8 (SCK1/CTS1/SDA1/PWM5A/GPIO10); also elsewhere on the board
D11_M4_MOTOR_FAULT: X4.9 (MOSI1/RTS1/SCL1/PWM5B/GPIO11); also elsewhere on the board
D12_X_DIR: X4.11 (HSTX/MISO1/TX0/SDA0/PWM6A/GPIO12); also elsewhere on the board
D13_Y_DIR: X4.12 (HSTX/CS1/RX0/SCL0/PWM6B/GPIO13); also elsewhere on the board
D14_Z_DIR: X4.13 (HSTX/SCK1/CTS0/SDA1/PWM7A/GPIO14); also elsewhere on the board
D15_A_DIR: X4.14 (HSTX/MOSI1/RTS0/SCL1/PWM7B/GPIO15); also elsewhere on the board
D16_Y2_DIR: X4.16 (HSTX/MISO0/TX0/SDA0/PWM0A/GPIO16); also elsewhere on the board
D17_X_STEP: X4.17 (HSTX/CS0/RX0/SCL0/PWM0B/GPIO17); also elsewhere on the board
D18_Y_STEP: X4.18 (HSTX/SCK0/CTS0/SDA1/PWM1A/GPIO18); also elsewhere on the board
D19_Z_STEP: X4.19 (XPI_CS1/HSTX/MOSI0/RTS0/SCL1/PWM1B/GPIO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); also elsewhere on the board
D20_A_STEP: X4.20 (MISO0/TX1/SDA0/PWM2A/GPIO20); also elsewhere on the board
D21_Y2_STEP: X4.21 (CS0/RX1/SCL0/PWM2B/GPIO21); also elsewhere on the board
D22_PROBE: X4.22 (SCK0/CTS1/SDA1/PWM3A/GPIO22); also elsewhere on the board
D23_TLS_PROBE: X4.23 (MOSI0/RTS1/SCL1/PWM3B/GPIO23); also elsewhere on the board
D24_XYA_HOME_EN: X4.25 (MISO1/TX1/SDA0/PWM4A/GPIO24); also elsewhere on the board
D25_Z_HOME_EN: X4.26 (CS1/RX1/SCL0/PWM4B/GPIO25); also elsewhere on the board
D26_SR0_OE: X4.27 (SCK1/CTS1/SDA1/PWM5A/GPIO26); also elsewhere on the board
D27_PWM_SPINDLE_DETECT: X4.28 (MOSI1/RTS1/SCL1/PWM5B/GPIO27); also elsewhere on the board
D28_LASER_ENABLE: X4.36 (MISO1/TX0/SDA0/PWM6A/GPIO28); also elsewhere on the board
D29_LASER_PWM: X4.37 (CS1/RX0/SCL0/PWM6B/GPIO29); also elsewhere on the board
D30_SDA: R3.2, X4.38 (SCK1/CTS0/SDA1/PWM7A/GPIO30); also elsewhere on the board
D31_SCL: R9.2, X4.39 (MOSI1/RTS0/SCL1/PWM7B/GPIO31); also elsewhere on the board
D32_SR0_OUT: X4.40 (GPIO32/MISO0/TX0/SDA0/PWM8A); also elsewhere on the board
D33_SR0_SCK: X4.42 (GPIO33/CS0/RX0/SCL0/PWM8B); also elsewhere on the board
D34_SR0_LCK: X4.43 (GPIO34/SCK0/CTS0/SDA1/PWM9A); also elsewhere on the board
D35_NEOPIXEL: X4.44 (GPIO35/MOSI0/RTS0/SCL1/PWM9B); also elsewhere on the board
D36_RS485_TXD: X4.45 (GPIO36/MISO0/TX1/SDA0/PWM10A); also elsewhere on the board
D37_RS485_RXD: X4.46 (GPIO37/CS0/RX1/SCL0/PWM10B); also elsewhere on the board
D38_RS485_DIR: X4.47 (GPIO38/SCK0/CTS1/SDA1/PWM11A); also elsewhere on the board
D39_E_STOP/HALT: X4.48 (GPIO39/MOSI0/RTS1/SCL1/PWM11B); also elsewhere on the board
D40_SPINDLE_PWM: X4.49 (GPIO40/ADC0/MISO1/TX1/SDA0/PWM8A); also elsewhere on the board
D41_ETHERNET_CS: X4.52 (GPIO41/ADC1/CS1/TX1/SCL0/PWM8B); also elsewhere on the board
D42_ETHERNET_IRQ: X4.53 (GPIO42/ADC2/SCK1/CTS1/SDA1/PWM9A); also elsewhere on the board
D43_SPI_MOSI: R28.2, SD3.3 (CMD(DI)), X4.54 (GPIO43/ADC3/MOSI1/RTS1/SCL1/PWM9B); also elsewhere on the board
D44_SPI_MISO: R63.2, SD3.7 (DAT0(DO)), X4.55 (GPIO44/ADC4/MISO1/TX0/SDA0/PWM10A); also elsewhere on the board
D45_SDCS: R10.1, R22.2, SD3.2 (CD/DAT3(!CS!)), X4.56 (GPIO45/ADC5/CS1/RX0/SCL0/PWM10B)
D46_SPI_SCK: R29.2, SD3.5 (CLK(SCLK)), X4.57 (GPIO46/ADC6/SCK1/CTS0/SDA1/PWM11A); also elsewhere on the board
D47_SPARE: X4.58 (GPIO47/ADC7/MOSI1/RTS0/SCL1/PWM11B); also elsewhere on the board
D+: R25.2, X4.67 (USB_D+)
D-: R24.2, X4.66 (USB_D-)
GND: SD3.S1, SD3.S2, SD3.S4; also elsewhere on the board
LX: L1.2, X4.63 (VREG_LX)
MCU_GND: C1.2, C2.2, C4.2, C5.1, C7.2, C8.1, C10.2, C11.2, C12.2, C14.1, C15.1, C16.2, C17.2, C18.2, C21.2, C22.2, C23.2, C24.2, C25.2, C26.1, C27.1, C33.1, D27.2 (GND), DEBUG.4, DEBUG.6, J14.GND, J14.GND2 (GND), J14.SHLD1 (SHLD), J14.SHLD2 (SHLD), J14.SHLD3 (SHLD), J14.SHLD4 (SHLD), J14.SHLD5 (SHLD), J14.SHLD6 (SHLD), J14.SHLD7 (SHLD), J14.SHLD8 (SHLD), R107.1, R108.1, S1.1, S2.1, SD3.6 (VSS), U6.4 (VSS), X4.62 (VREG_PGND), X4.MNT (GND); also elsewhere on the board
unnamed: D12.C, R10.2
unnamed: C27.2, R23.1, Y1.2
NC: SD3.S3
QSPI_CS: R17.1, R26.1, U6.1 (SSEL), X4.75 (!QSPI_CS)
QSPI_DATA[0]: U6.5 (MOSI), X4.72 (QSPI_SD0)
QSPI_DATA[1]: U6.2 (MISO), X4.74 (QSPI_SD1)
QSPI_DATA[2]: U6.3 (WP#/IO2), X4.73 (QSPI_SD2)
QSPI_DATA[3]: U6.7 (HOLD#/IO3), X4.70 (QSPI_SD3)
QSPI_SCK: U6.6 (SCK), X4.71 (QSPI_SCLK)
SWCLK: DEBUG.3, X4.33 (SWCLK)
SWDIO: DEBUG.1, X4.34 (SWDIO)
USBBOOT: R26.2, S2.2
USBC_CC1: J14.A5 (CC1), R108.2
USBC_CC2: J14.B5 (CC2), R107.2
USB_D_N: L13.3, R24.1
USB_D_P: L13.2, R25.1
VBUS: C5.2, C7.1, D27.5 (VBUS), J14.VBUS1 (VBUS), J14.VBUS2 (VBUS); also elsewhere on the board
VCC_MCU_3V3: C2.1, C10.1, C11.1, C12.1, C17.1, C18.1, C21.1, C22.1, C23.1, C24.1, C25.1, D12.A, DEBUG.2, R3.1, R4.2, R5.1, R9.1, R17.2, R21.1, R22.1, R28.1, R29.1, R63.1, SD3.4 (VDD), U6.8 (VCC), X4.5 (IOVDD), X4.15 (IOVDD), X4.24 (IOVDD), X4.29 (IOVDD), X4.41 (IOVDD), X4.50 (IOVDD), X4.60 (IOVDD), X4.64 (VREG_VIN), X4.68 (USB_OTP_VDD), X4.69 (QSPI_IOVDD), X4.76 (IOVDD); also elsewhere on the board
VREG_AVDD: C4.1, R5.2, X4.61 (VREG_AVDD)
XIN: C26.2, X4.30 (XIN), Y1.1
XOUT: R23.2, X4.31 (XOUT)

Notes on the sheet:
USB
MCU
EEPROM
SD CARD
DFU/RESET
DEBUG

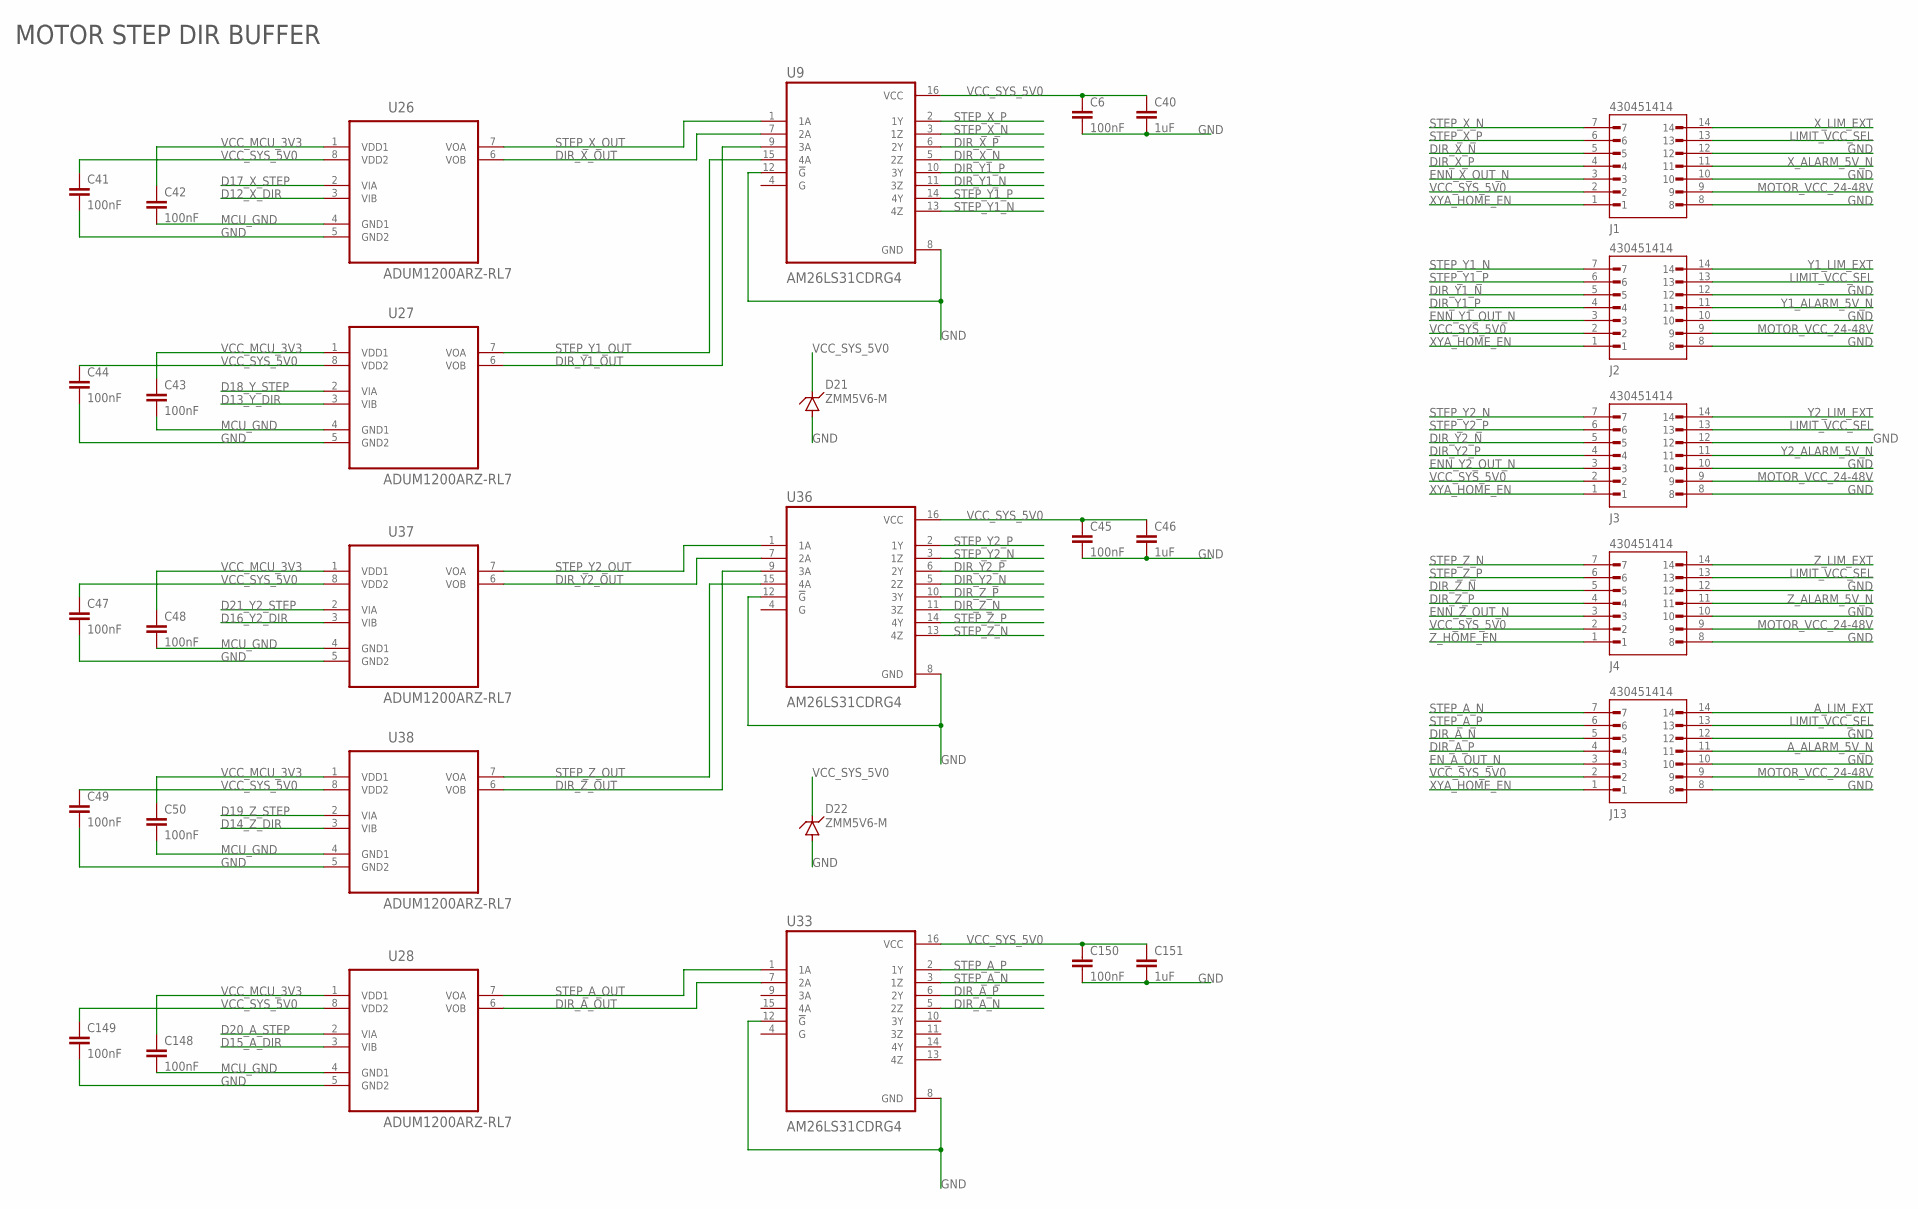
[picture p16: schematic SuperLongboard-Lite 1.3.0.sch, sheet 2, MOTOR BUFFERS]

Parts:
C6, C41, C42, C43, C44, C45, C47, C48, C49, C50, C148, C149, C150: 100nF; C0603K
C40, C46, C151: 1uF; C0603K
D21, D22: ZMM5V6-M; MINIMELF
J1, J2, J3, J4, J13: 430451414; MOLEX_430451414
U9, U33, U36: AM26LS31CDRG4; SOIC127P600X175-16N
U26, U27, U28, U37, U38: ADUM1200ARZ-RL7; SOIC127P600X175-8N

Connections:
A_ALARM_5V_N: J13.11; also elsewhere on the board
A_LIM_EXT: J13.14; also elsewhere on the board
D12_X_DIR: U26.3 (VIB); also elsewhere on the board
D13_Y_DIR: U27.3 (VIB); also elsewhere on the board
D14_Z_DIR: U38.3 (VIB); also elsewhere on the board
D15_A_DIR: U28.3 (VIB); also elsewhere on the board
D16_Y2_DIR: U37.3 (VIB); also elsewhere on the board
D17_X_STEP: U26.2 (VIA); also elsewhere on the board
D18_Y_STEP: U27.2 (VIA); also elsewhere on the board
D19_Z_STEP: U38.2 (VIA); also elsewhere on the board
D20_A_STEP: U28.2 (VIA); also elsewhere on the board
D21_Y2_STEP: U37.2 (VIA); also elsewhere on the board
DIR_A_N: J13.5, U33.5 (2Z)
DIR_A_OUT: U28.6 (VOB), U33.7 (2A)
DIR_A_P: J13.4, U33.6 (2Y)
DIR_X_N: J1.5, U9.5 (2Z)
DIR_X_OUT: U9.7 (2A), U26.6 (VOB)
DIR_X_P: J1.4, U9.6 (2Y)
DIR_Y1_N: J2.5, U9.11 (3Z)
DIR_Y1_OUT: U9.9 (3A), U27.6 (VOB)
DIR_Y1_P: J2.4, U9.10 (3Y)
DIR_Y2_N: J3.5, U36.5 (2Z)
DIR_Y2_OUT: U36.7 (2A), U37.6 (VOB)
DIR_Y2_P: J3.4, U36.6 (2Y)
DIR_Z_N: J4.5, U36.11 (3Z)
DIR_Z_OUT: U36.9 (3A), U38.6 (VOB)
DIR_Z_P: J4.4, U36.10 (3Y)
ENN_X_OUT_N: J1.3; also elsewhere on the board
ENN_Y1_OUT_N: J2.3; also elsewhere on the board
ENN_Y2_OUT_N: J3.3; also elsewhere on the board
ENN_Z_OUT_N: J4.3; also elsewhere on the board
EN_A_OUT_N: J13.3; also elsewhere on the board
GND: C6.2, C40.2, C41.2, C44.2, C45.2, C46.2, C47.2, C49.2, C149.2, C150.2, C151.2, D21.A, D22.A, J1.8, J1.10, J1.12, J2.8, J2.10, J2.12, J3.8, J3.10, J3.12, J4.8, J4.10, J4.12, J13.8, J13.10, J13.12, U9.8 (GND), U9.12 (!G), U26.5 (GND2), U27.5 (GND2), U28.5 (GND2), U33.8 (GND), U33.12 (!G), U36.8 (GND), U36.12 (!G), U37.5 (GND2), U38.5 (GND2); also elsewhere on the board
LIMIT_VCC_SEL: J1.13, J2.13, J3.13, J4.13, J13.13; also elsewhere on the board
MCU_GND: C42.2, C43.2, C48.2, C50.2, C148.2, U26.4 (GND1), U27.4 (GND1), U28.4 (GND1), U37.4 (GND1), U38.4 (GND1); also elsewhere on the board
MOTOR_VCC_24-48V: J1.9, J2.9, J3.9, J4.9, J13.9; also elsewhere on the board
STEP_A_N: J13.7, U33.3 (1Z)
STEP_A_OUT: U28.7 (VOA), U33.1 (1A)
STEP_A_P: J13.6, U33.2 (1Y)
STEP_X_N: J1.7, U9.3 (1Z)
STEP_X_OUT: U9.1 (1A), U26.7 (VOA)
STEP_X_P: J1.6, U9.2 (1Y)
STEP_Y1_N: J2.7, U9.13 (4Z)
STEP_Y1_OUT: U9.15 (4A), U27.7 (VOA)
STEP_Y1_P: J2.6, U9.14 (4Y)
STEP_Y2_N: J3.7, U36.3 (1Z)
STEP_Y2_OUT: U36.1 (1A), U37.7 (VOA)
STEP_Y2_P: J3.6, U36.2 (1Y)
STEP_Z_N: J4.7, U36.13 (4Z)
STEP_Z_OUT: U36.15 (4A), U38.7 (VOA)
STEP_Z_P: J4.6, U36.14 (4Y)
VCC_MCU_3V3: C42.1, C43.1, C48.1, C50.1, C148.1, U26.1 (VDD1), U27.1 (VDD1), U28.1 (VDD1), U37.1 (VDD1), U38.1 (VDD1); also elsewhere on the board
VCC_SYS_5V0: C6.1, C40.1, C41.1, C44.1, C45.1, C46.1, C47.1, C49.1, C149.1, C150.1, C151.1, D21.C, D22.C, J1.2, J2.2, J3.2, J4.2, J13.2, U9.16 (VCC), U26.8 (VDD2), U27.8 (VDD2), U28.8 (VDD2), U33.16 (VCC), U36.16 (VCC), U37.8 (VDD2), U38.8 (VDD2); also elsewhere on the board
XYA_HOME_EN: J1.1, J2.1, J3.1, J13.1; also elsewhere on the board
X_ALARM_5V_N: J1.11; also elsewhere on the board
X_LIM_EXT: J1.14; also elsewhere on the board
Y1_ALARM_5V_N: J2.11; also elsewhere on the board
Y1_LIM_EXT: J2.14; also elsewhere on the board
Y2_ALARM_5V_N: J3.11; also elsewhere on the board
Y2_LIM_EXT: J3.14; also elsewhere on the board
Z_ALARM_5V_N: J4.11; also elsewhere on the board
Z_HOME_EN: J4.1; also elsewhere on the board
Z_LIM_EXT: J4.14; also elsewhere on the board

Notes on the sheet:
MOTOR STEP DIR BUFFER

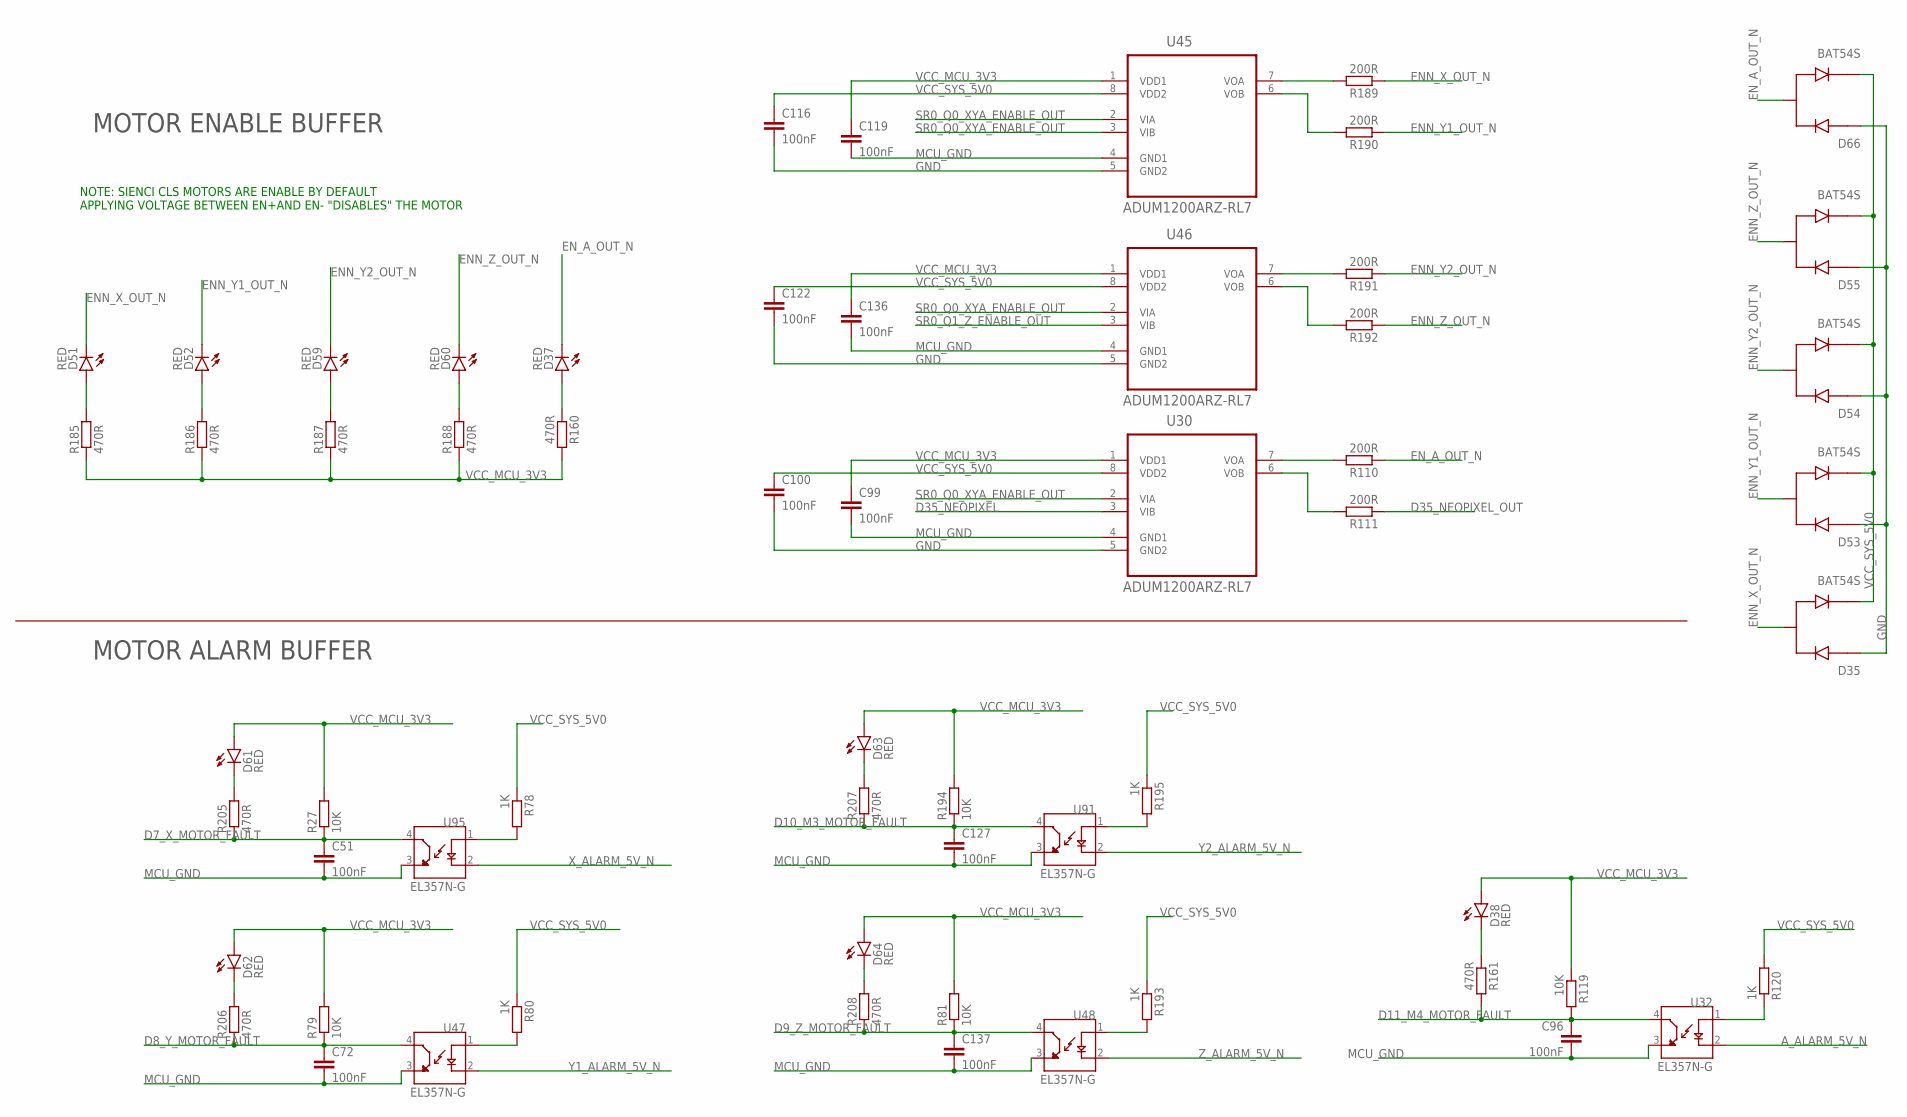
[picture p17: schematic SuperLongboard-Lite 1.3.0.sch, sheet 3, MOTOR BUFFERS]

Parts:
C51, C72, C96, C127, C137: 100nF; C0603
C99, C100, C116, C119, C122, C136: 100nF; C0603K
D35, D53, D54, D55, D66: BAT54S; SOT95P240X120-3N
D37, D38, D51, D52, D59, D60, D61, D62, D63, D64: RED; CHIP-LED0805
R27, R79, R81, R119, R194: 10K; R0603
R78, R80, R120, R193, R195: 1K; R0603
R110, R111, R189, R190, R191, R192: 200R; R0603
R160, R161, R185, R186, R187, R188, R205, R206, R207, R208: 470R; R0603
U30, U45, U46: ADUM1200ARZ-RL7; SOIC127P600X175-8N
U32, U47, U48, U91, U95: EL357N-G; OPTO_EL357N-G

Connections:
A_ALARM_5V_N: U32.2 (C); also elsewhere on the board
D7_X_MOTOR_FAULT: C51.1, R27.1, R205.1, U95.4 (CT); also elsewhere on the board
D8_Y_MOTOR_FAULT: C72.1, R79.1, R206.1, U47.4 (CT); also elsewhere on the board
D9_Z_MOTOR_FAULT: C137.1, R81.1, R208.1, U48.4 (CT); also elsewhere on the board
D10_M3_MOTOR_FAULT: C127.1, R194.1, R207.1, U91.4 (CT); also elsewhere on the board
D11_M4_MOTOR_FAULT: C96.1, R119.2, R161.2, U32.4 (CT); also elsewhere on the board
D35_NEOPIXEL: U30.3 (VIB); also elsewhere on the board
D35_NEOPIXEL_OUT: R111.1; also elsewhere on the board
ENN_X_OUT_N: D35.3, D51.C, R189.1; also elsewhere on the board
ENN_Y1_OUT_N: D52.C, D53.3, R190.1; also elsewhere on the board
ENN_Y2_OUT_N: D54.3, D59.C, R191.1; also elsewhere on the board
ENN_Z_OUT_N: D55.3, D60.C, R192.1; also elsewhere on the board
EN_A_OUT_N: D37.C, D66.3, R110.1; also elsewhere on the board
GND: C100.2, C116.2, C122.2, D35.1, D53.1, D54.1, D55.1, D66.1, U30.5 (GND2), U45.5 (GND2), U46.5 (GND2); also elsewhere on the board
MCU_GND: C51.2, C72.2, C96.2, C99.2, C119.2, C127.2, C136.2, C137.2, U30.4 (GND1), U32.3 (ET), U45.4 (GND1), U46.4 (GND1), U47.3 (ET), U48.3 (ET), U91.3 (ET), U95.3 (ET); also elsewhere on the board
unnamed: R189.2, U45.7 (VOA)
unnamed: R190.2, U45.6 (VOB)
unnamed: R191.2, U46.7 (VOA)
unnamed: R192.2, U46.6 (VOB)
unnamed: D62.C, R206.2
unnamed: R78.2, U95.1 (A)
unnamed: D61.C, R205.2
unnamed: R80.2, U47.1 (A)
unnamed: D63.C, R207.2
unnamed: R195.2, U91.1 (A)
unnamed: D64.C, R208.2
unnamed: R193.2, U48.1 (A)
unnamed: D51.A, R185.2
unnamed: D52.A, R186.2
unnamed: D37.A, R160.1
unnamed: D60.A, R188.2
unnamed: D59.A, R187.2
unnamed: R110.2, U30.7 (VOA)
unnamed: R111.2, U30.6 (VOB)
unnamed: R120.1, U32.1 (A)
unnamed: D38.C, R161.1
SR0_Q0_XYA_ENABLE_OUT: U30.2 (VIA), U45.2 (VIA), U45.3 (VIB), U46.2 (VIA); also elsewhere on the board
SR0_Q1_Z_ENABLE_OUT: U46.3 (VIB); also elsewhere on the board
VCC_MCU_3V3: C99.1, C119.1, C136.1, D38.A, D61.A, D62.A, D63.A, D64.A, R27.2, R79.2, R81.2, R119.1, R160.2, R185.1, R186.1, R187.1, R188.1, R194.2, U30.1 (VDD1), U45.1 (VDD1), U46.1 (VDD1); also elsewhere on the board
VCC_SYS_5V0: C100.1, C116.1, C122.1, D35.2, D53.2, D54.2, D55.2, D66.2, R78.1, R80.1, R120.2, R193.1, R195.1, U30.8 (VDD2), U45.8 (VDD2), U46.8 (VDD2); also elsewhere on the board
X_ALARM_5V_N: U95.2 (C); also elsewhere on the board
Y1_ALARM_5V_N: U47.2 (C); also elsewhere on the board
Y2_ALARM_5V_N: U91.2 (C); also elsewhere on the board
Z_ALARM_5V_N: U48.2 (C); also elsewhere on the board

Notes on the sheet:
MOTOR ENABLE BUFFER
MOTOR ALARM BUFFER
NOTE: SIENCI CLS MOTORS ARE ENABLE BY DEFAULT APPLYING VOLTAGE BETWEEN EN+AND EN- "DISABLES" THE MOTOR

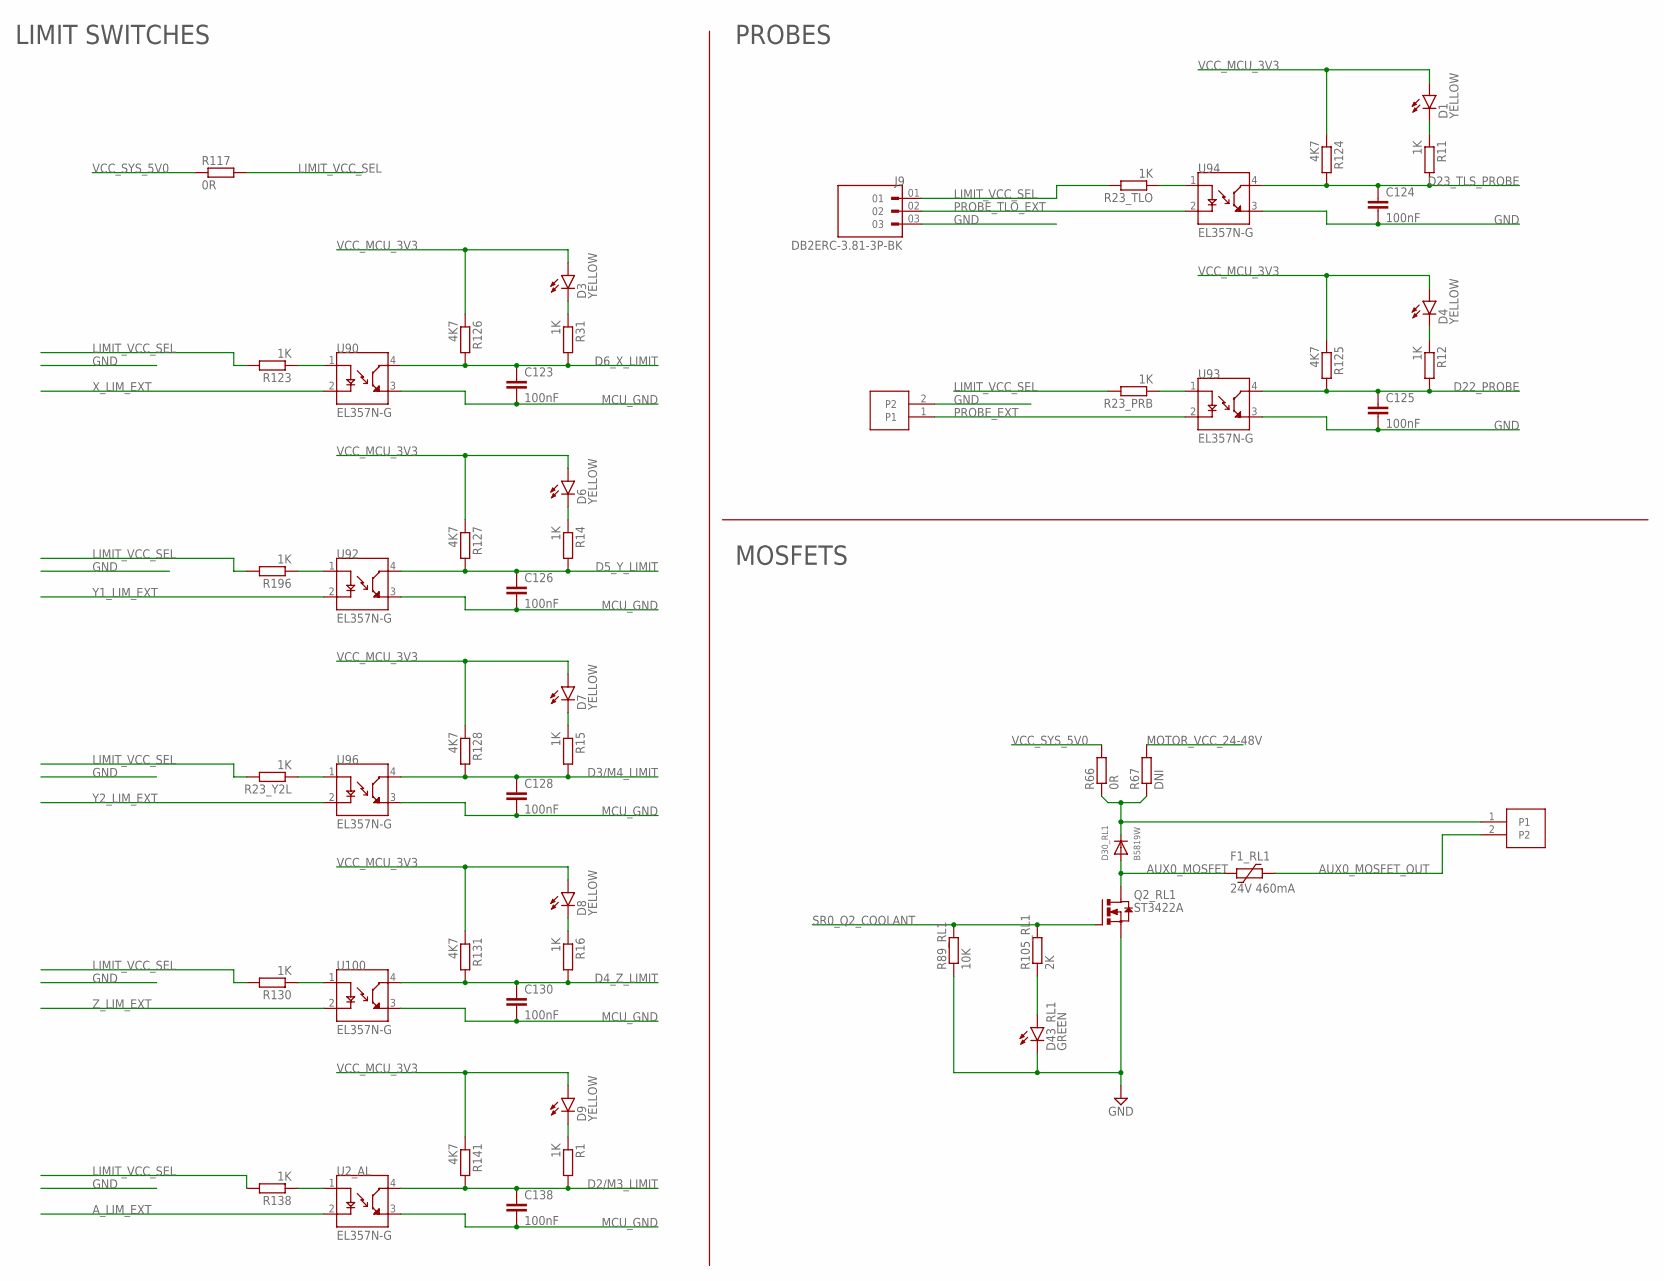
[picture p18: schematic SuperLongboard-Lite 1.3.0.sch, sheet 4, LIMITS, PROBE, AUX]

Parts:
C123, C124, C125, C126, C128, C130, C138: 100nF; C0603
D1, D3, D4, D6, D7, D8, D9: YELLOW; CHIP-LED0805
D30_RL1: B5819W; SOD123FL
D43_RL1: GREEN; CHIP-LED0805
F1_RL1: 24V 460mA; 1206L
J9: DB2ERC-3.81-3P-BK; PHOENIX_1803280
J12, J17: DB2ERC-3.81-2P-BK; MC1.5/2-G-3.81
Q2_RL1: ST3422A; SOT-23
R1, R11, R12, R14, R15, R16, R23_PRB, R23_TLO, R23_Y2L, R31, R123, R130, R138, R196: 1K; R0603
R66, R117: 0R; R0603
R67: DNI; R0603
R89_RL1: 10K; R0603
R105_RL1: 2K; R0603
R124, R125, R126, R127, R128, R131, R141: 4K7; R0603
U2_AL, U90, U92, U93, U94, U96, U100: EL357N-G; OPTO_EL357N-G

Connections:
AUX0_MOSFET: D30_RL1.A, F1_RL1.2, Q2_RL1.P3 (D)
AUX0_MOSFET_OUT: F1_RL1.1, J17.2
A_LIM_EXT: U2_AL.2 (C); also elsewhere on the board
D2/M3_LIMIT: C138.1, R1.2, R141.2, U2_AL.4 (CT); also elsewhere on the board
D3/M4_LIMIT: C128.1, R15.2, R128.2, U96.4 (CT); also elsewhere on the board
D4_Z_LIMIT: C130.1, R16.2, R131.2, U100.4 (CT); also elsewhere on the board
D5_Y_LIMIT: C126.1, R14.2, R127.2, U92.4 (CT); also elsewhere on the board
D6_X_LIMIT: C123.1, R31.2, R126.2, U90.4 (CT); also elsewhere on the board
D22_PROBE: C125.1, R12.2, R125.2, U93.4 (CT); also elsewhere on the board
D23_TLS_PROBE: C124.1, R11.2, R124.2, U94.4 (CT); also elsewhere on the board
GND: C124.2, C125.2, D43_RL1.C, J9.03, J12.2, Q2_RL1.P2 (S), R89_RL1.1, U93.3 (ET), U94.3 (ET); also elsewhere on the board
LIMIT_VCC_SEL: J9.01, R23_PRB.2, R23_TLO.2, R23_Y2L.2, R117.2, R123.2, R130.2, R138.2, R196.2; also elsewhere on the board
MCU_GND: C123.2, C126.2, C128.2, C130.2, C138.2, U2_AL.3 (ET), U90.3 (ET), U92.3 (ET), U96.3 (ET), U100.3 (ET); also elsewhere on the board
MOTOR_VCC_24-48V: R67.2; also elsewhere on the board
unnamed: D3.C, R31.1
unnamed: D30_RL1.C, J17.1, R66.1, R67.1
unnamed: D43_RL1.A, R105_RL1.1
unnamed: R23_TLO.1, U94.1 (A)
unnamed: D1.C, R11.1
unnamed: R23_PRB.1, U93.1 (A)
unnamed: D4.C, R12.1
unnamed: R123.1, U90.1 (A)
unnamed: R196.1, U92.1 (A)
unnamed: D6.C, R14.1
unnamed: R23_Y2L.1, U96.1 (A)
unnamed: D7.C, R15.1
unnamed: R130.1, U100.1 (A)
unnamed: D8.C, R16.1
unnamed: R138.1, U2_AL.1 (A)
unnamed: D9.C, R1.1
PROBE_EXT: J12.1, U93.2 (C)
PROBE_TLO_EXT: J9.02, U94.2 (C)
SR0_Q2_COOLANT: Q2_RL1.P1 (G), R89_RL1.2, R105_RL1.2; also elsewhere on the board
VCC_MCU_3V3: D1.A, D3.A, D4.A, D6.A, D7.A, D8.A, D9.A, R124.1, R125.1, R126.1, R127.1, R128.1, R131.1, R141.1; also elsewhere on the board
VCC_SYS_5V0: R66.2, R117.1; also elsewhere on the board
X_LIM_EXT: U90.2 (C); also elsewhere on the board
Y1_LIM_EXT: U92.2 (C); also elsewhere on the board
Y2_LIM_EXT: U96.2 (C); also elsewhere on the board
Z_LIM_EXT: U100.2 (C); also elsewhere on the board

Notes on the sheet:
LIMIT SWITCHES
PROBES
MOSFETS

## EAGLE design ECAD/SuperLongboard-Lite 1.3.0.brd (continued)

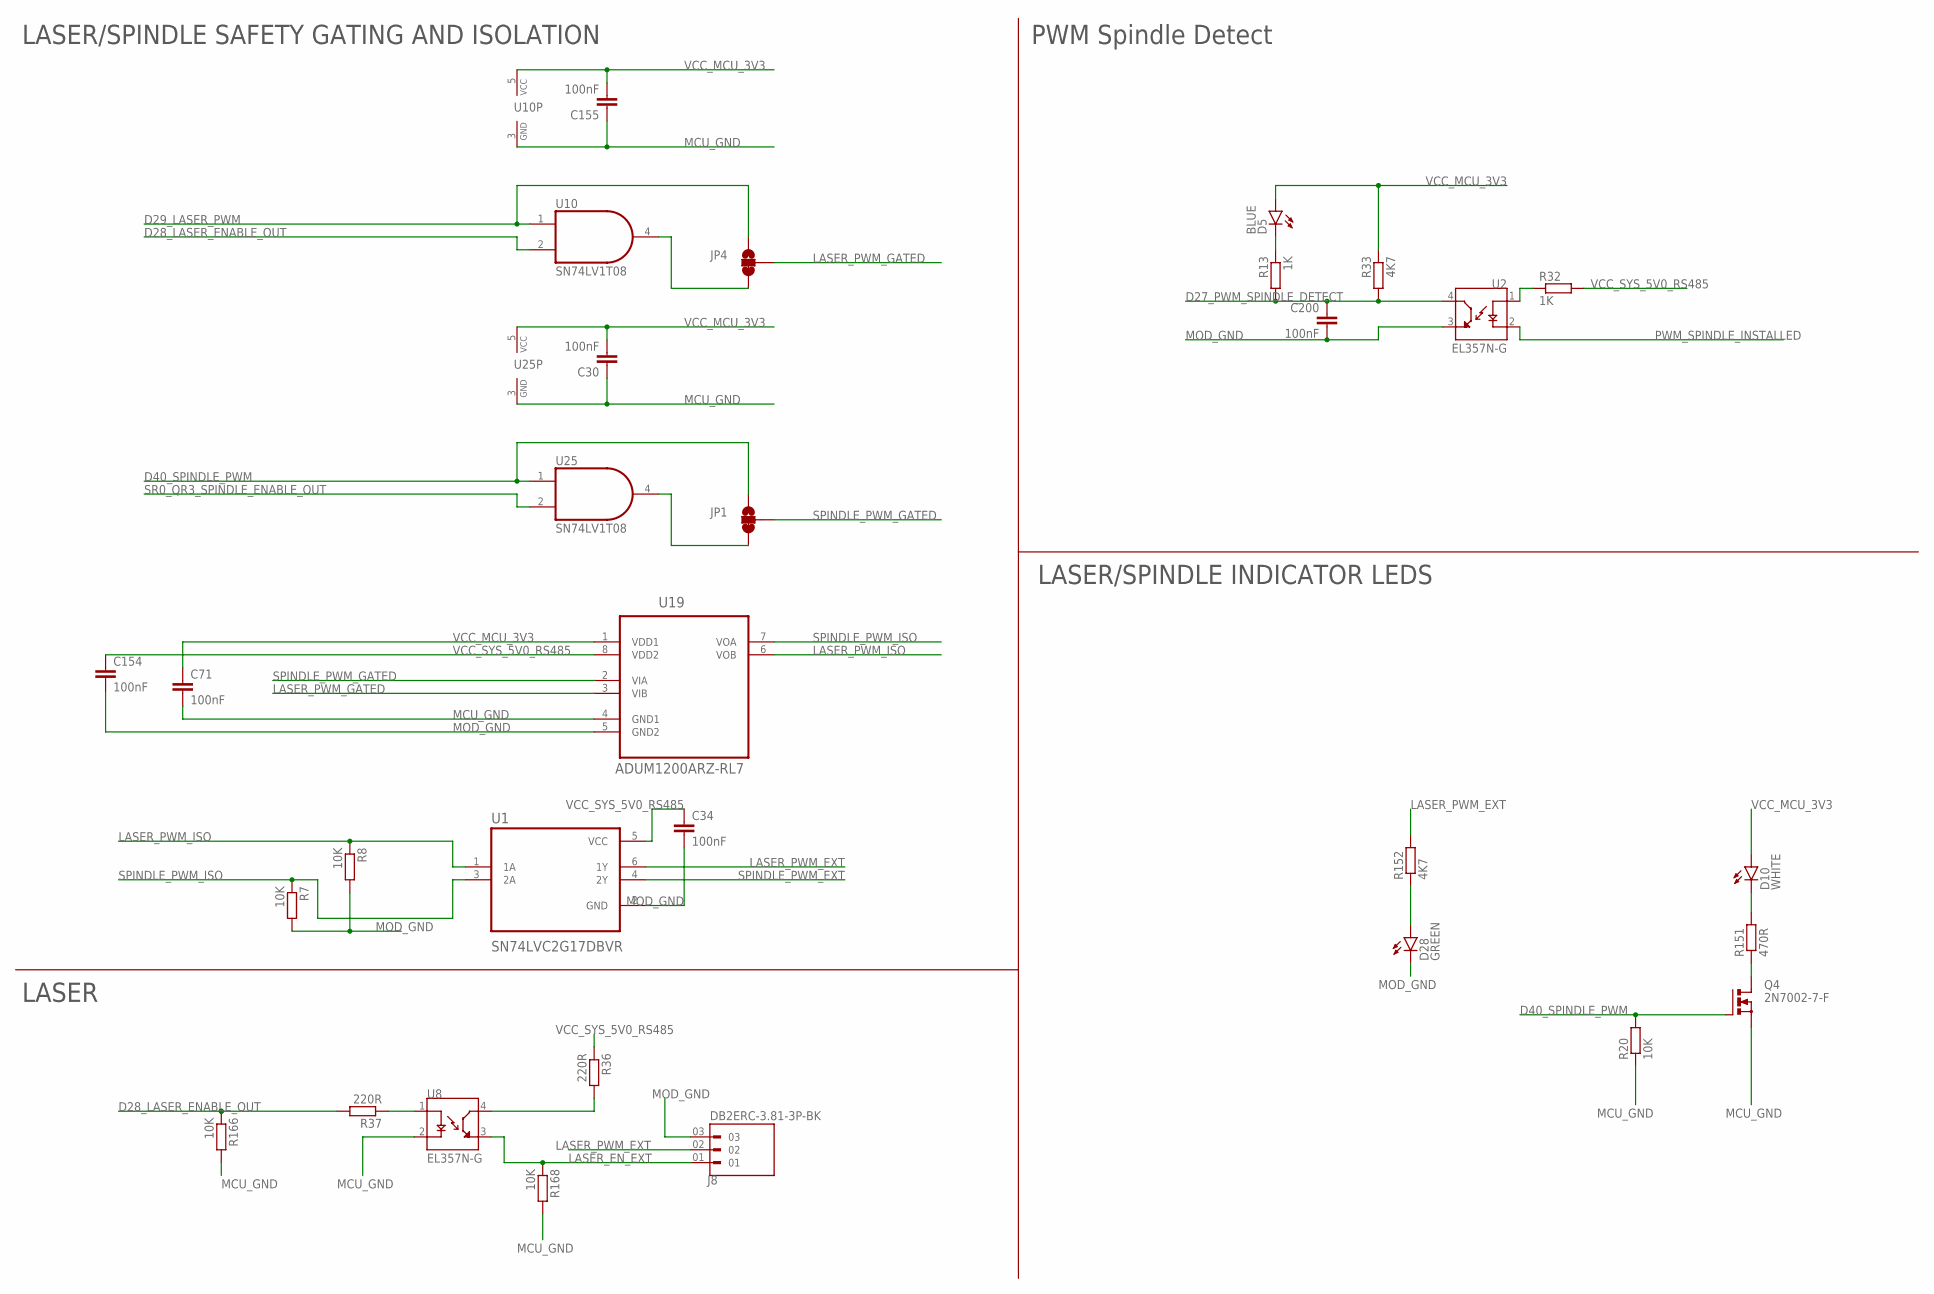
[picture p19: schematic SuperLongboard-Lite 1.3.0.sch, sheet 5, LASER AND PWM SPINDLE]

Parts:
C30, C155, C200: 100nF; C0603
C34: 100nF; C0603; LCSC_PART C14663
C71, C154: 100nF; C0603K
D5: BLUE; CHIP-LED0805
D10: WHITE; CHIP-LED0805
D28: GREEN; CHIP-LED0805
J8: DB2ERC-3.81-3P-BK; PHOENIX_1803280
JP1, JP4: DNI; SMT-JUMPER_3_1-NC_TRACE_SILK
Q4: 2N7002-7-F; SOT-23
R7, R8, R20, R166, R168: 10K; R0603
R13, R32: 1K; R0603
R33, R152: 4K7; R0603
R36, R37: 220R; R0603
R151: 470R; R0603
U1: SN74LVC2G17DBVR; SOT95P280X145-6N
U2, U8: EL357N-G; OPTO_EL357N-G
U10, U25: SN74LV1T08; SOT23-5
U19: ADUM1200ARZ-RL7; SOIC127P600X175-8N

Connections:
D27_PWM_SPINDLE_DETECT: C200.1, R13.2, R33.2, U2.4 (CT); also elsewhere on the board
D28_LASER_ENABLE_OUT: R37.2, R166.1, U10.2 (I1); also elsewhere on the board
D29_LASER_PWM: JP4.1, U10.1 (I0); also elsewhere on the board
D40_SPINDLE_PWM: JP1.1, Q4.P1 (G), R20.2, U25.1 (I0); also elsewhere on the board
LASER_EN_EXT: J8.01, R168.1, U8.3 (ET)
LASER_PWM_EXT: J8.02, R152.2, U1.6 (1Y)
LASER_PWM_GATED: JP4.2, U19.3 (VIB)
LASER_PWM_ISO: R8.1, U1.1 (1A), U19.6 (VOB)
MCU_GND: C30.1, C71.2, C155.1, Q4.P2 (S), R20.1, R166.2, R168.2, U8.2 (C), U10.3 (GND), U19.4 (GND1), U25.3 (GND); also elsewhere on the board
MOD_GND: C34.2, C154.2, C200.2, D28.C, J8.03, R7.2, R8.2, U1.2 (GND), U2.3 (ET), U19.5 (GND2); also elsewhere on the board
unnamed: R32.1, U2.1 (A)
unnamed: JP1.3, U25.4 (O)
unnamed: D10.C, R151.2
unnamed: Q4.P3 (D), R151.1
unnamed: JP4.3, U10.4 (O)
unnamed: D5.C, R13.1
unnamed: D28.A, R152.1
unnamed: R37.1, U8.1 (A)
unnamed: R36.2, U8.4 (CT)
PWM_SPINDLE_INSTALLED: U2.2 (C); also elsewhere on the board
SPINDLE_PWM_EXT: U1.4 (2Y); also elsewhere on the board
SPINDLE_PWM_GATED: JP1.2, U19.2 (VIA)
SPINDLE_PWM_ISO: R7.1, U1.3 (2A), U19.7 (VOA)
SR0_QR3_SPINDLE_ENABLE_OUT: U25.2 (I1); also elsewhere on the board
VCC_MCU_3V3: C30.2, C71.1, C155.2, D5.A, D10.A, R33.1, U10.5 (VCC), U19.1 (VDD1), U25.5 (VCC); also elsewhere on the board
VCC_SYS_5V0_RS485: C34.1, C154.1, R32.2, R36.1, U1.5 (VCC), U19.8 (VDD2); also elsewhere on the board

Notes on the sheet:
LASER
PWM Spindle Detect
LASER/SPINDLE SAFETY GATING AND ISOLATION
LASER/SPINDLE INDICATOR LEDS

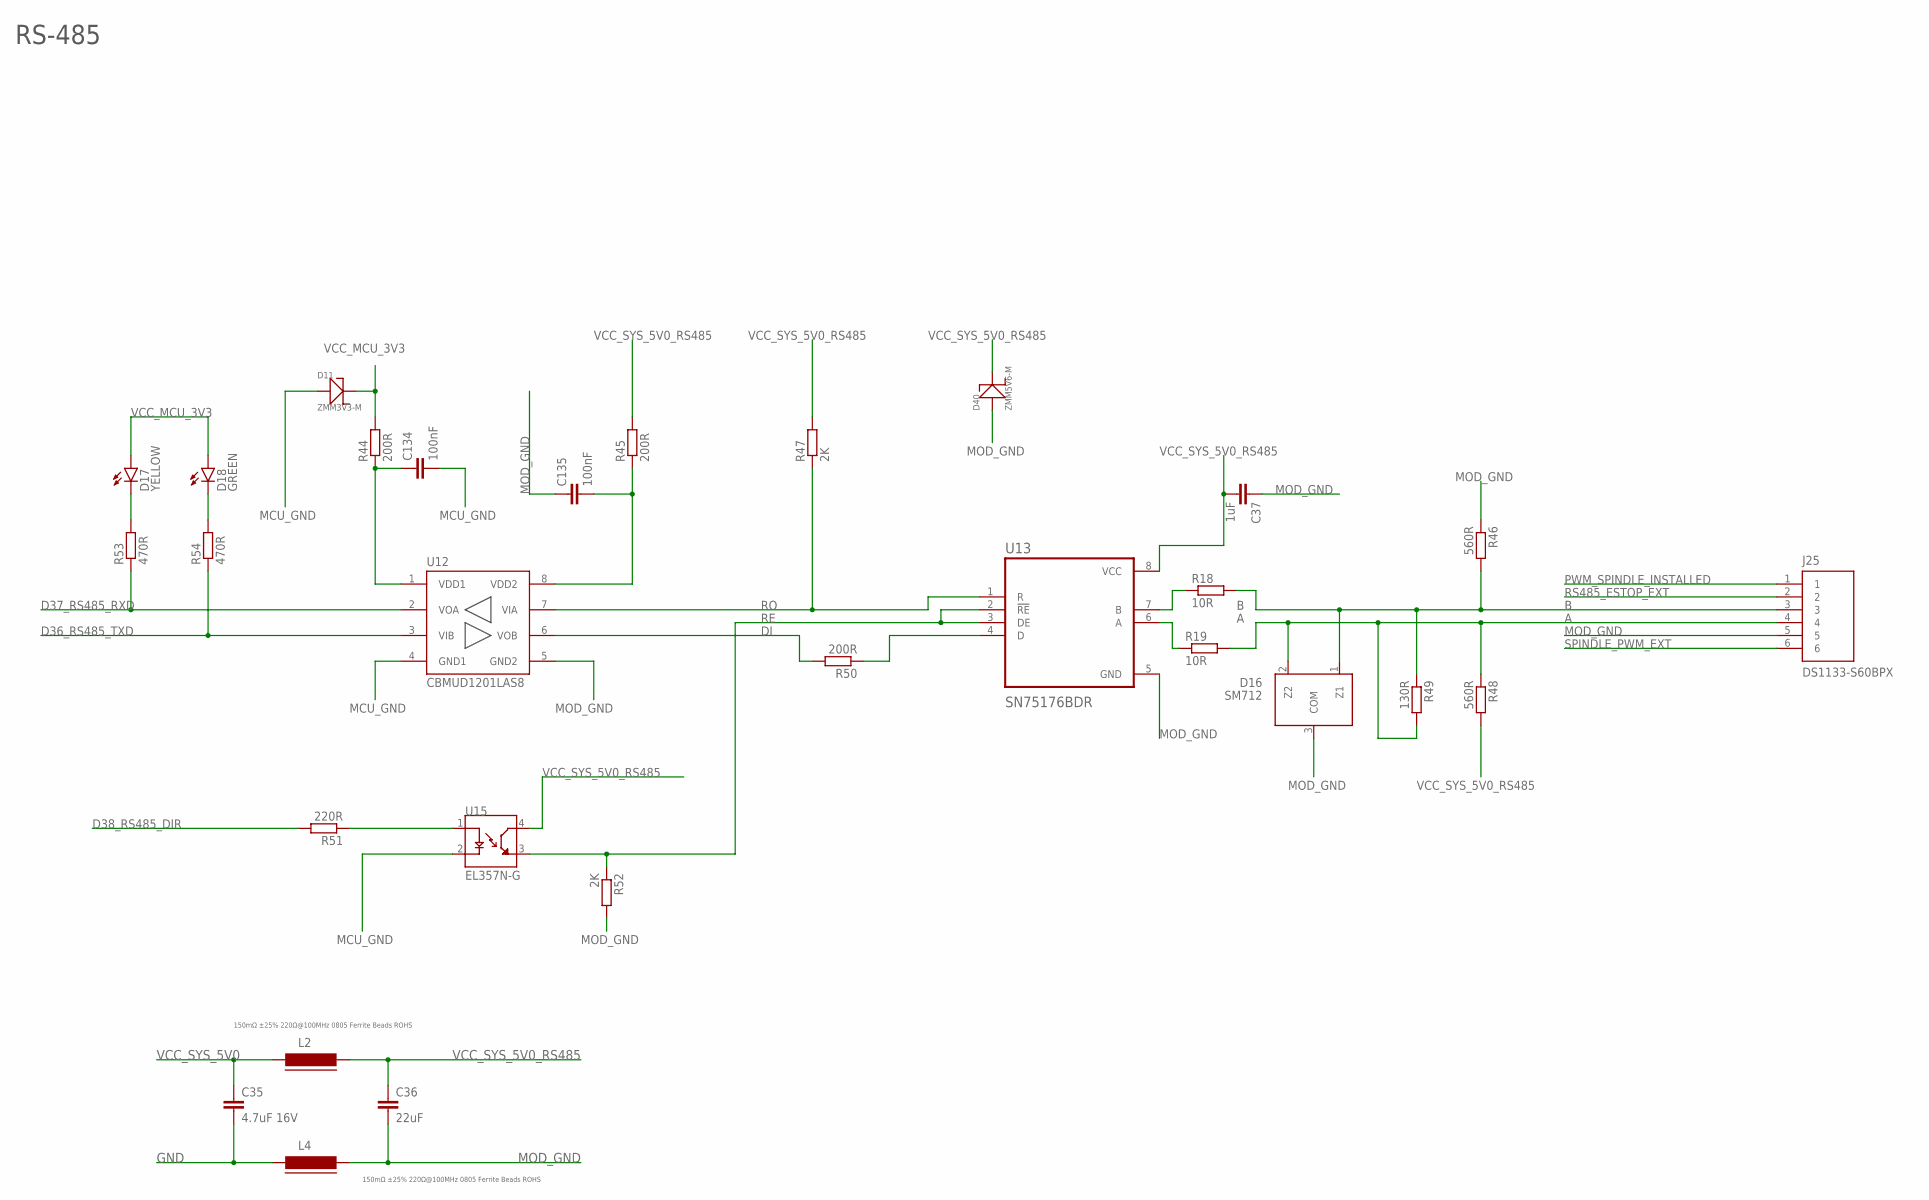
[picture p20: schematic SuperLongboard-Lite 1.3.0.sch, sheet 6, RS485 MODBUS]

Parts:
C35: 4.7uF 16V; C0603
C36: 22uF; C0603; LCSC_PART C59461
C37: 1uF; C0603; LCSC_PART C15849
C134, C135: 100nF; C0603; LCSC_PART C14663
D11: ZMM3V3-M; LL-34
D16: SM712; SOT23
D17: YELLOW; CHIP-LED0805
D18: GREEN; CHIP-LED0805
D40: ZMM5V6-M; LL-34
J25: DS1133-S60BPX; KH-PCB-6P6C
L2, L4: 150mΩ ±25% 220Ω@100MHz 0805 Ferrite Beads ROHS; FB805; LCSC_PART C139188
R18, R19: 10R; R0603
R44, R45, R50: 200R; R0603
R46, R48: 560R; R0603
R47, R52: 2K; R0603
R49: 130R; R0805
R51: 220R; R0603
R53, R54: 470R; R0603
U12: CBMUD1201LAS8; SOIC-8
U13: SN75176BDR; SOIC127P599X175-8N
U15: EL357N-G; OPTO_EL357N-G

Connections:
A: D16.2 (Z2), J25.4, R19.2, R48.1, R49.2
B: D16.1 (Z1), J25.3, R18.2, R46.2, R49.1
D36_RS485_TXD: R54.1, U12.3 (VIB); also elsewhere on the board
D37_RS485_RXD: R53.1, U12.2 (VOA); also elsewhere on the board
D38_RS485_DIR: R51.2; also elsewhere on the board
DI: R50.2, U12.6 (VOB)
GND: C35.2, L4.1; also elsewhere on the board
MCU_GND: C134.2, D11.A (+), U12.4 (GND1), U15.2 (C); also elsewhere on the board
MOD_GND: C36.2, C37.1, C135.1, D16.3 (COM), D40.A (+), J25.5, L4.2, R46.1, R52.2, U12.5 (GND2), U13.5 (GND); also elsewhere on the board
unnamed: R18.1, U13.7 (B)
unnamed: R19.1, U13.6 (A)
unnamed: C134.1, R44.1, U12.1 (VDD1)
unnamed: C135.2, R45.1, U12.8 (VDD2)
unnamed: R50.1, U13.4 (D)
unnamed: R51.1, U15.1 (A)
unnamed: D17.C, R53.2
unnamed: D18.C, R54.2
PWM_SPINDLE_INSTALLED: J25.1; also elsewhere on the board
RE: R52.1, U13.2 (!RE), U13.3 (DE), U15.3 (ET)
RO: R47.1, U12.7 (VIA), U13.1 (R)
RS485_ESTOP_EXT: J25.2; also elsewhere on the board
SPINDLE_PWM_EXT: J25.6; also elsewhere on the board
VCC_MCU_3V3: D11.C (-), D17.A, D18.A, R44.2; also elsewhere on the board
VCC_SYS_5V0: C35.1, L2.1; also elsewhere on the board
VCC_SYS_5V0_RS485: C36.1, C37.2, D40.C (-), L2.2, R45.2, R47.2, R48.2, U13.8 (VCC), U15.4 (CT); also elsewhere on the board

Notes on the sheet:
RS-485

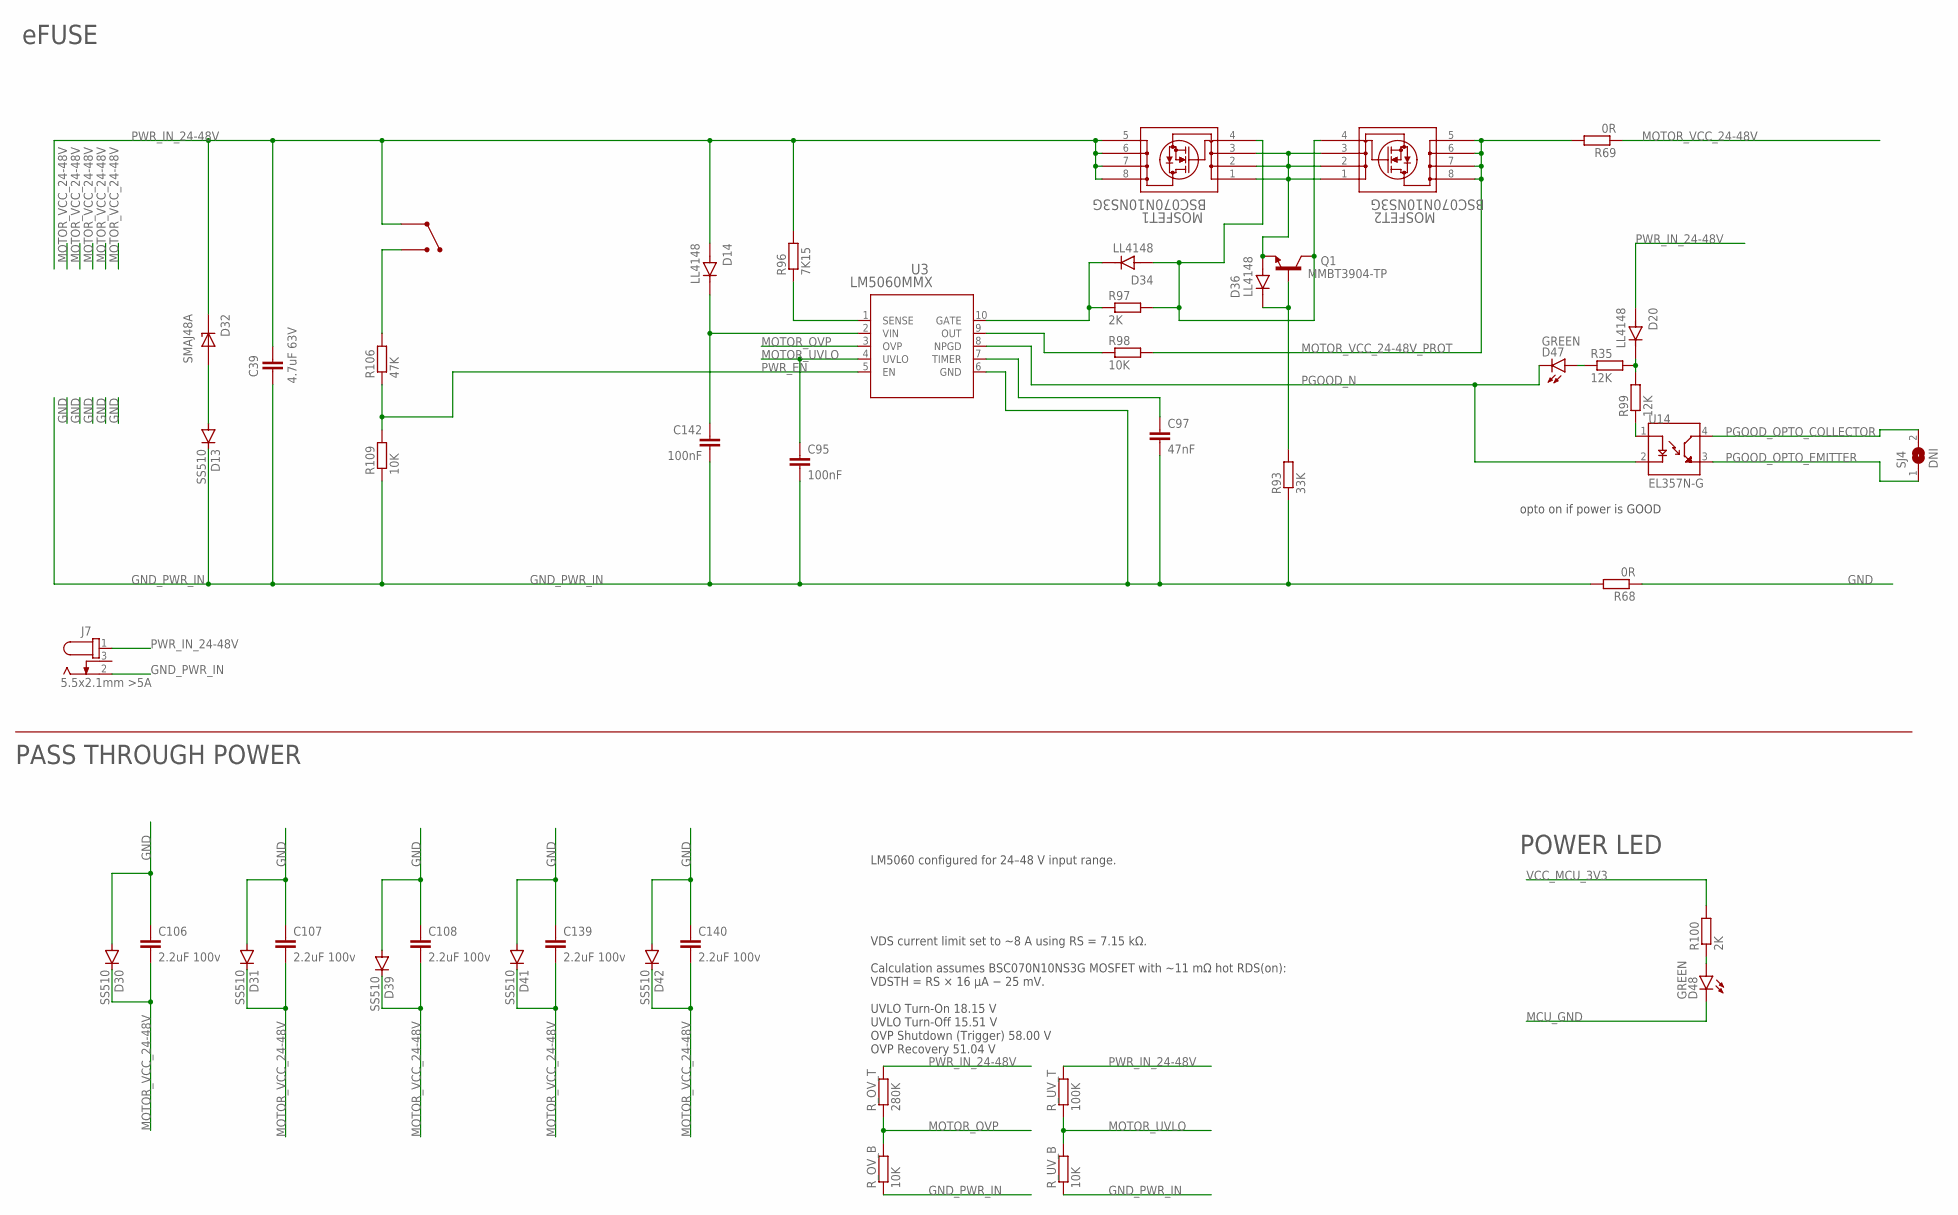
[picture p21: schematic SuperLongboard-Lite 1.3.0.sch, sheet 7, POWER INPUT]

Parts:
C39: 4.7uF 63V; C1210; LCSC_PART C47783
C95, C142: 100nF; C0603; LCSC_PART C28233
C97: 47nF; C0805; LCSC_PART C53134
C106, C107, C108, C139, C140: 2.2uF 100v; C1210; LCSC_PART C576517
D13, D30, D31, D39, D41, D42: SS510; DO-214AC
D14, D20, D34, D36: LL4148; DIO_LL4148
D32: SMAJ48A; DIOM4325X250N
D47, D48: GREEN; CHIP-LED0805
J7: 5.5x2.1mm >5A; 694108301002
MOSFET1, MOSFET2: BSC070N10NS3G; QNMOS_PRPAK5X6_HUA
Q1: MMBT3904-TP; SOT95P237X125-3N
R35, R99: 12K; R0805
R68, R69: 0R; R0603
R93: 33K; R0805
R96: 7K15; R1206
R97, R100: 2K; R0603
R98, R109: 10K; R0603
R106: 47K; R0805
R_OV_B: 10K; R0603
R_OV_T: 280K; R0805
R_UV_B: 10K; R0603
R_UV_T: 100K; R0805
SJ4: DNI; SJ
SW1: KCD11-BL
U3: LM5060MMX; MUB10A
U14: EL357N-G; OPTO_EL357N-G

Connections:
GND: C106.1, C107.1, C108.1, C139.1, C140.1, D30.A, D31.A, D39.A, D41.A, D42.A, R68.1; also elsewhere on the board
GND_PWR_IN: C39.2, C95.2, C97.2, C142.2, D13.C, J7.2, R68.2, R93.1, R109.1, R_OV_B.1, R_UV_B.1, U3.6 (GND)
MCU_GND: D48.C; also elsewhere on the board
MOTOR_OVP: R_OV_B.2, R_OV_T.1, U3.3 (OVP)
MOTOR_UVLO: C95.1, R_UV_B.2, R_UV_T.1, U3.4 (UVLO)
MOTOR_VCC_24-48V: C106.2, C107.2, C108.2, C139.2, C140.2, D30.C, D31.C, D39.C, D41.C, D42.C, R69.1; also elsewhere on the board
MOTOR_VCC_24-48V_PROT: MOSFET2.5, MOSFET2.6, MOSFET2.7, MOSFET2.8, R69.2, R98.2
unnamed: D47.A, R35.1
unnamed: R96.1, U3.1 (SENSE)
unnamed: D34.C, R97.1, U3.10 (GATE)
unnamed: D36.C, Q1.1 (B), R93.2
unnamed: R98.1, U3.9 (OUT)
unnamed: C97.1, U3.7 (TIMER)
unnamed: D20.C, R35.2, R99.2
unnamed: D34.A, MOSFET1.4, MOSFET2.4, Q1.3 (C), R97.2
unnamed: C142.1, D14.C, U3.2 (VIN)
unnamed: D13.A, D32.A
unnamed: R99.1, U14.1 (A)
unnamed: D36.A, MOSFET1.1, MOSFET1.2, MOSFET1.3, MOSFET2.1, MOSFET2.2, MOSFET2.3, Q1.2 (E)
unnamed: D48.A, R100.1
unnamed: R106.2, SW1.P$2
PGOOD_N: D47.C, U3.8 (NPGD), U14.2 (C)
PGOOD_OPTO_COLLECTOR: SJ4.2, U14.4 (CT); also elsewhere on the board
PGOOD_OPTO_EMITTER: SJ4.1, U14.3 (ET); also elsewhere on the board
PWR_EN: R106.1, R109.2, U3.5 (EN)
PWR_IN_24-48V: C39.1, D14.A, D20.A, D32.C, J7.1, MOSFET1.5, MOSFET1.6, MOSFET1.7, MOSFET1.8, R96.2, R_OV_T.2, R_UV_T.2, SW1.P$1
VCC_MCU_3V3: R100.2; also elsewhere on the board

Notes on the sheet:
eFUSE
LM5060 configured for 24–48 V input range. VDS current limit set to ~8 A using RS = 7.15 kΩ. Calculation assumes BSC070N10NS3G MOSFET with ~11 mΩ hot RDS(on): VDSTH = RS × 16 µA − 25 mV. UVLO Turn-On 18.15 V UVLO Turn-Off 15.51 V OVP Shutdown (Trigger) 58.00 V OVP Recovery 51.04 V
opto on if power is GOOD
POWER LED
PASS THROUGH POWER

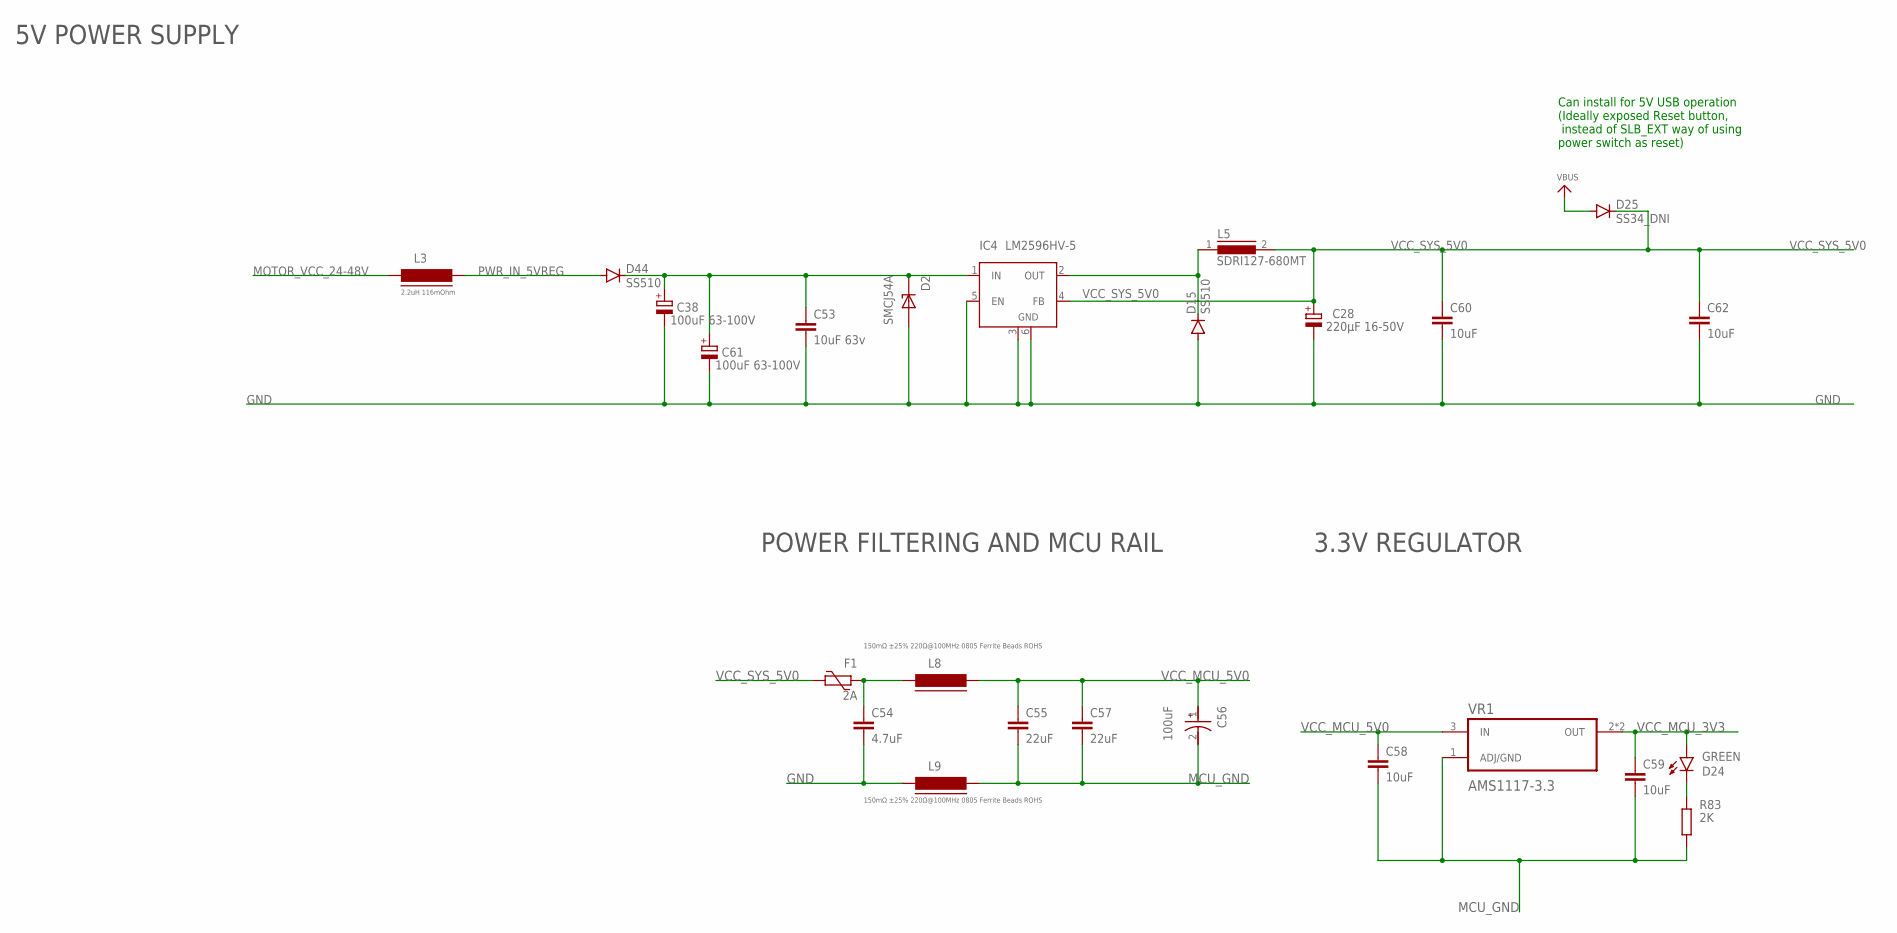
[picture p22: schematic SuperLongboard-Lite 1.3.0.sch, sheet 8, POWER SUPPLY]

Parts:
C28: 220µF 16-50V; PANASONIC_E
C38, C61: 100uF 63-100V; PANASONIC_E
C53: 10uF 63v; C1206; LCSC_PART C13585
C54: 4.7uF; C0603
C55, C57: 22uF; C0603; LCSC_PART C59461
C56: 100uF; CAPMP3528X210N
C58, C59, C60, C62: 10uF; C1206; LCSC_PART C13585
D2: SMCJ54A; DIOM7959X262N
D15, D44: SS510; DO-214AC
D24: GREEN; CHIP-LED0805
D25: SS34_DNI; DO-214AC
F1: 2A; 1206L
IC4: LM2596HV-5; TO263-5
L3: 2.2uH 116mOhm; FB805; LCSC_PART C139188
L5: SDRI127-680MT; DR127
L8, L9: 150mΩ ±25% 220Ω@100MHz 0805 Ferrite Beads ROHS; FB805; LCSC_PART C139188
R83: 2K; R0603
VR1: AMS1117-3.3

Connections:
+24V1: C38.+, C53.1, C61.+, D2.C, D44.C, IC4.1 (IN)
GND: C28.-, C38.-, C53.2, C54.2, C60.2, C61.-, C62.2, D2.A, D15.A, IC4.3 (GND), IC4.5 (EN), IC4.6 (GND), L9.1; also elsewhere on the board
MCU_GND: C55.2, C56.2, C57.2, C58.2, C59.2, L9.2, R83.2, VR1.1 (ADJ/GND); also elsewhere on the board
MOTOR_VCC_24-48V: L3.1; also elsewhere on the board
unnamed: D24.C, R83.1
unnamed: D15.C, IC4.2 (OUT), L5.1
PWR_IN_5VREG: D44.A, L3.2
SYS5V: C54.1, F1.2, L8.1
VBUS: D25.A; also elsewhere on the board
VCC_MCU_3V3: C59.1, D24.A, VR1.2 (OUT), VR1.4 (OUT); also elsewhere on the board
VCC_MCU_5V0: C55.1, C56.1, C57.1, C58.1, L8.2, VR1.3 (IN)
VCC_SYS_5V0: C28.+, C60.1, C62.1, D25.C, F1.1, IC4.4 (FB), L5.2; also elsewhere on the board

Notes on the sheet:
POWER FILTERING AND MCU RAIL
3.3V REGULATOR
5V POWER SUPPLY
Can install for 5V USB operation (Ideally exposed Reset button, instead of SLB_EXT way of using power switch as reset)

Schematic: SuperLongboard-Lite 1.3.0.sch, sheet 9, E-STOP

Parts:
C3, C9, C13, C19, C20, C29, C31: 100nF; C0603; LCSC_PART C14663
D2_ESTOP_MCU: RED; CHIP-LED0805
E_STOPIN: 74HC08D-T; SOIC127P600X175-14N
J10: B2B-XH-A_(LF)(SN); JST_B2B-XH-A_(LF)(SN)
J11: DB2ERC-3.81-2P-BK; MC1.5/2-G-3.81
JP2: DNI; SMT-JUMPER_3_1-NC_TRACE_SILK
L12: 150mΩ ±25% 220Ω@100MHz 0805 Ferrite Beads ROHS; FB805; LCSC_PART C139188
R2, R34, R43, R56, R58, R64: 10K; R0603
R30, R40, R57: 510R; R0603
R38, R41: 120R; R0603
R55: 220R; R0603
R61: 2K; R0603
U11, U16, U22, U23: EL357N-G; OPTO_EL357N-G
U20_EGATE: 74HC08D-T; SOIC127P600X175-14N

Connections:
D28_LASER_ENABLE: U20_EGATE.2 (1B); also elsewhere on the board
D28_LASER_ENABLE_OUT: U20_EGATE.3 (1Y); also elsewhere on the board
D39_E_STOP/HALT: C19.1, E_STOPIN.11 (4Y), R61.1, R64.1, U20_EGATE.1 (1A), U20_EGATE.4 (2A), U20_EGATE.9 (3A), U20_EGATE.12 (4A), U22.2 (C); also elsewhere on the board
ESTOP1_LV: C13.1, E_STOPIN.1 (1A), R56.2, U16.3 (ET)
ESTOP3_LV: C3.1, E_STOPIN.4 (2A), R34.1, U11.4 (CT)
ESTOP5_LV: C31.1, E_STOPIN.9 (3A), R58.1, U23.4 (CT)
ESTOP_AUX: U11.2 (C); also elsewhere on the board
ESTOP_CONTROLLER: J10.1, R40.2
ESTOP_EXT: J11.1, R57.2
GND: U16.2 (C), U23.2 (C); also elsewhere on the board
MCU_GND: C3.2, C9.2, C13.2, C19.2, C20.2, C29.2, C31.2, E_STOPIN.7 (GND), R2.1, R56.1, U11.3 (ET), U20_EGATE.7 (GND), U23.3 (ET); also elsewhere on the board
MOD_GND: U22.3 (ET); also elsewhere on the board
unnamed: R30.1, U11.1 (A)
unnamed: R55.1, U22.1 (A)
unnamed: R40.1, U16.1 (A)
unnamed: E_STOPIN.6 (2Y), E_STOPIN.10 (3B)
unnamed: E_STOPIN.3 (1Y), E_STOPIN.12 (4A)
unnamed: E_STOPIN.8 (3Y), E_STOPIN.13 (4B)
unnamed: R41.1, U16.4 (CT)
unnamed: R57.1, U23.1 (A)
unnamed: D2_ESTOP_MCU.C, R61.2
unnamed: JP2.1, U20_EGATE.11 (4Y)
PGOOD_OPTO_COLLECTOR: R38.1; also elsewhere on the board
PGOOD_OPTO_EMITTER: C9.1, E_STOPIN.2 (1B), R2.2; also elsewhere on the board
RS485_ESTOP_EXT: U22.4 (CT); also elsewhere on the board
SPARE_ESTOP: E_STOPIN.5 (2B), R43.1
SR0_Q0_XYA_ENABLE: U20_EGATE.10 (3B); also elsewhere on the board
SR0_Q0_XYA_ENABLE_OUT: U20_EGATE.8 (3Y); also elsewhere on the board
SR0_Q1_Z_ENABLE: JP2.3, U20_EGATE.13 (4B); also elsewhere on the board
SR0_Q1_Z_ENABLE_OUT: JP2.2; also elsewhere on the board
SR0_QR3_SPINDLE_ENABLE: U20_EGATE.5 (2B); also elsewhere on the board
SR0_QR3_SPINDLE_ENABLE_OUT: U20_EGATE.6 (2Y); also elsewhere on the board
VCC_ESTOP_5V0: J10.2, J11.2, L12.1, R30.2
VCC_MCU_3V3: C20.1, C29.1, D2_ESTOP_MCU.A, E_STOPIN.14 (VCC), R34.2, R38.2, R41.2, R43.2, R55.2, R58.2, R64.2, U20_EGATE.14 (VCC); also elsewhere on the board
VCC_SYS_5V0: L12.2; also elsewhere on the board

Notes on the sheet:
HIGH - IF NO ESTOPS ARE ACTIVATED LOW - IF ANY ESTOP IS ACTIVATED
EMERGENCY STOPS
SIGNAL TO GRBLHAL
GATED ENABLE SIGNALS FOR CLS MOTORS, LASER, PWM SPINDLE
E-STOP OUTPUT FOR RS485 SPINDLE
PRIMARY E-STOP INPUT - CLOSED LOOP - OPENS ON PROBLEM
SIGNALS FROM MCU TO BE GATED BY E-STOP
PGOOD E-STOP INPUT -CLOSED LOOP - OPENS ON PROBLEM
AUX/ATCPTC E-STOP INPUT - OPEN LOOP - CLOSES ON PROBLEM
EXTERNAL/PANEL MOUNT/REMOTE E-STOP INPUT OPEN LOOP - CLOSES ON PROBLEM

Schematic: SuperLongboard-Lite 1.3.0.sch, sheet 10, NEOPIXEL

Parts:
C101, C102: 100nF; C0603; LCSC_PART C14663
F4: 2A; 1206L
J6, J16: B3B-XH-A(LF)(SN); JST_B3B-XH-A(LF)(SN)
WC4, WC5, WC6, WC7, WC8, WC9, WC10, WC11, WC12, WC13, WC14, WC15: 100nF; C0603; LCSC_PART C14663
WL4, WL5, WL6, WL7, WL8, WL9, WL10, WL11, WL12, WL13, WL14, WL15: WS2812-2020; LED_WS2812-2020

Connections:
D35_NEOPIXEL_OUT: WL4.3 (DIN); also elsewhere on the board
GND: C101.2, C102.2, J6.1, J16.1, WC4.2, WC5.2, WC6.2, WC7.2, WC8.2, WC9.2, WC10.2, WC11.2, WC12.2, WC13.2, WC14.2, WC15.2, WL4.2 (VSS), WL5.2 (VSS), WL6.2 (VSS), WL7.2 (VSS), WL8.2 (VSS), WL9.2 (VSS), WL10.2 (VSS), WL11.2 (VSS), WL12.2 (VSS), WL13.2 (VSS), WL14.2 (VSS), WL15.2 (VSS); also elsewhere on the board
unnamed: WL4.1 (DOUT), WL5.3 (DIN)
unnamed: WL5.1 (DOUT), WL6.3 (DIN)
unnamed: WL6.1 (DOUT), WL7.3 (DIN)
unnamed: WL7.1 (DOUT), WL8.3 (DIN)
unnamed: WL8.1 (DOUT), WL9.3 (DIN)
unnamed: WL9.1 (DOUT), WL10.3 (DIN)
unnamed: WL10.1 (DOUT), WL11.3 (DIN)
unnamed: WL11.1 (DOUT), WL12.3 (DIN)
unnamed: WL12.1 (DOUT), WL13.3 (DIN)
unnamed: WL13.1 (DOUT), WL14.3 (DIN)
unnamed: WL14.1 (DOUT), WL15.3 (DIN)
unnamed: J6.2, J16.2, WL15.1 (DOUT)
NEOPIXEL_5V: C101.1, C102.1, F4.2, J6.3, J16.3, WC4.1, WC5.1, WC6.1, WC7.1, WC8.1, WC9.1, WC10.1, WC11.1, WC12.1, WC13.1, WC14.1, WC15.1, WL4.4 (VDD), WL5.4 (VDD), WL6.4 (VDD), WL7.4 (VDD), WL8.4 (VDD), WL9.4 (VDD), WL10.4 (VDD), WL11.4 (VDD), WL12.4 (VDD), WL13.4 (VDD), WL14.4 (VDD), WL15.4 (VDD)
VCC_SYS_5V0: F4.1; also elsewhere on the board

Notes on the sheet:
NEOPIXELS

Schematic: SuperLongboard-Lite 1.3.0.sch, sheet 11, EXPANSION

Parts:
C93: 100nF; C0603; LCSC_PART C14663
IC1_SREXP: 74HC595; SOIC-16
J5: Connector IDC Header Through Hole 26 position 2.5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; 61202621621
R6, R59, R82: 100R; R0603
R65: 10k; R0603
R70: 100K; R0805

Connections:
D0_UART0_RX: J5.5; also elsewhere on the board
D1_UART0_TX: J5.7; also elsewhere on the board
D26_SR0_OE: IC1_SREXP.13 (!OE), J5.21, R65.1; also elsewhere on the board
D30_SDA: J5.11; also elsewhere on the board
D31_SCL: J5.13; also elsewhere on the board
D32_SR0_OUT: R6.1; also elsewhere on the board
D33_SR0_SCK: J5.15, R82.1; also elsewhere on the board
D34_SR0_LCK: J5.17, R59.1; also elsewhere on the board
D35_NEOPIXEL: J5.9; also elsewhere on the board
D41_ETHERNET_CS: J5.8, R70.1; also elsewhere on the board
D42_ETHERNET_IRQ: J5.10; also elsewhere on the board
D43_SPI_MOSI: J5.4; also elsewhere on the board
D44_SPI_MISO: J5.2; also elsewhere on the board
D46_SPI_SCK: J5.6; also elsewhere on the board
D47_SPARE: J5.14; also elsewhere on the board
ESTOP_AUX: J5.23; also elsewhere on the board
GND: C93.2, J5.1, J5.12, J5.26, R70.2; also elsewhere on the board
MCU_GND: IC1_SREXP.8 (GND); also elsewhere on the board
MOTOR_VCC_24-48V: J5.25; also elsewhere on the board
unnamed: IC1_SREXP.12 (LATCH), R59.2
unnamed: IC1_SREXP.11 (SCLK), R82.2
unnamed: IC1_SREXP.14 (SDA), R6.2
SR0_OUT: IC1_SREXP.9 (Q7S), J5.19
SR0_Q0_XYA_ENABLE: IC1_SREXP.15 (Q0); also elsewhere on the board
SR0_Q1_Z_ENABLE: IC1_SREXP.1 (Q1); also elsewhere on the board
SR0_Q2_COOLANT: IC1_SREXP.2 (Q2); also elsewhere on the board
SR0_QR3_SPINDLE_ENABLE: IC1_SREXP.3 (Q3), J5.16; also elsewhere on the board
SR0_QR4_SPARE: IC1_SREXP.4 (Q4), J5.18
SR0_QR5_SPARE: IC1_SREXP.5 (Q5), J5.20
SR0_QR6_SPARE: IC1_SREXP.6 (Q6), J5.22
SR0_QR7_SPARE: IC1_SREXP.7 (Q7), J5.24
VCC_MCU_3V3: C93.1, IC1_SREXP.10 (!RST), IC1_SREXP.16 (V+), R65.2; also elsewhere on the board
VCC_SYS_5V0: J5.3; also elsewhere on the board

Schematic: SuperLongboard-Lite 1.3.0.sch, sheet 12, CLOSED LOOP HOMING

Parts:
C32, C52: 100nF; C0603K
D19, D29: GREEN; CHIP-LED0805
R39, R42: 200R; R0603
R60, R74: 2K; R0603
R62, R75: 10K; R0603
U4: ADUM1200ARZ-RL7; SOIC127P600X175-8N

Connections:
D24_XYA_HOME_EN: D19.C, R75.1, U4.2 (VIA); also elsewhere on the board
D25_Z_HOME_EN: D29.C, R62.1, U4.3 (VIB); also elsewhere on the board
GND: C52.2, U4.5 (GND2); also elsewhere on the board
MCU_GND: C32.2, U4.4 (GND1); also elsewhere on the board
unnamed: R39.2, U4.7 (VOA)
unnamed: R42.2, U4.6 (VOB)
unnamed: D29.A, R60.1
unnamed: D19.A, R74.1
VCC_MCU_3V3: C32.1, R60.2, R62.2, R74.2, R75.2, U4.1 (VDD1); also elsewhere on the board
VCC_SYS_5V0: C52.1, U4.8 (VDD2); also elsewhere on the board
XYA_HOME_EN: R39.1; also elsewhere on the board
Z_HOME_EN: R42.1; also elsewhere on the board

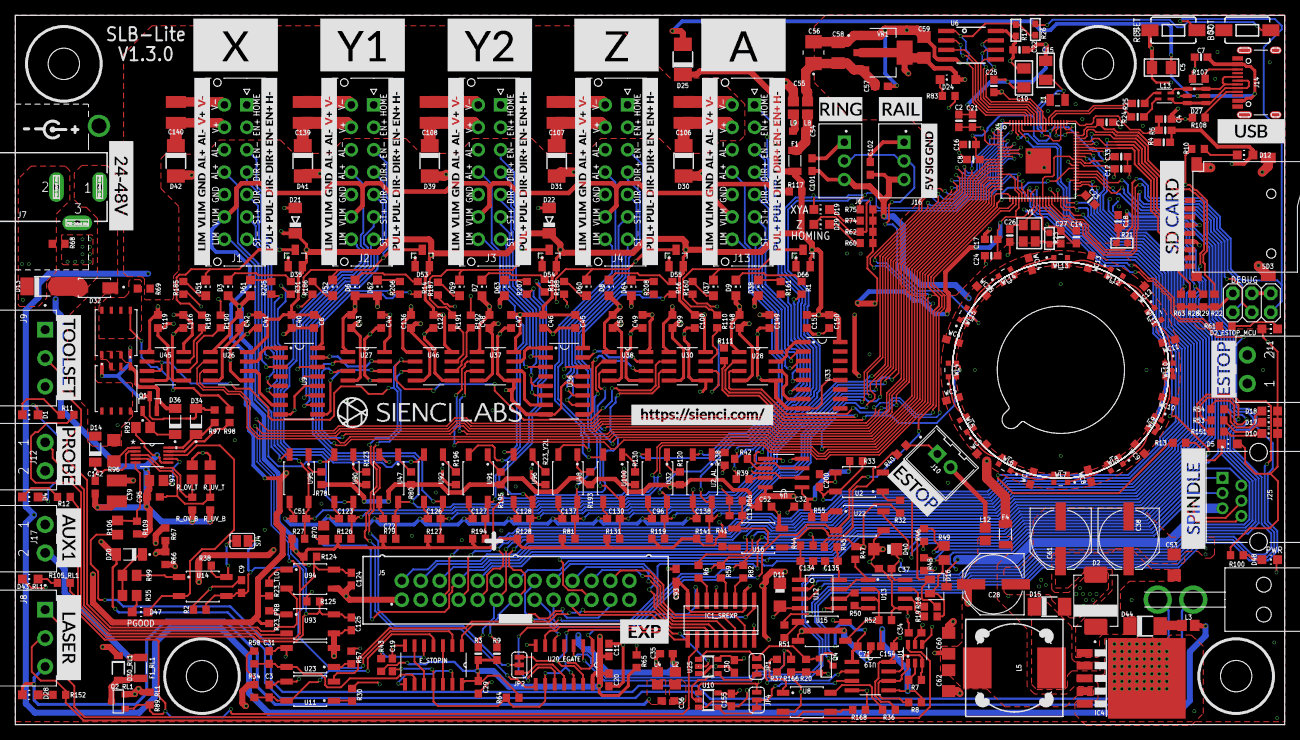
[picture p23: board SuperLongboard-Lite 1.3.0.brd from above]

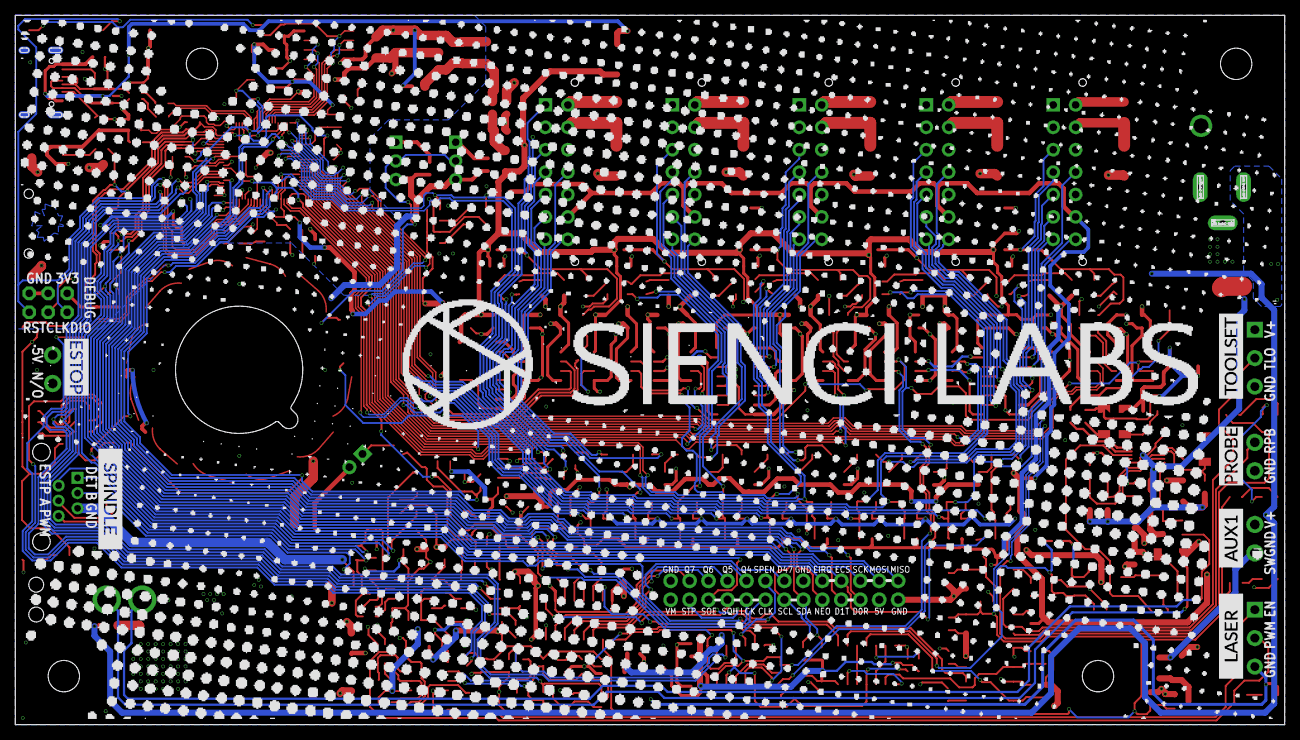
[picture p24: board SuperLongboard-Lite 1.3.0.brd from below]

Board: 4 copper layers, 170.0 x 95.0 mm, 441 parts (6 on the bottom side), 283 nets.

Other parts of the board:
U$1: Z
U$3, U$6, U$18, U$21, U$26: LIM__VLIM__GND__AL#__AL#__V#__V#
U$4, U$36: AUX1
U$5, U$17, U$20, U$22, U$27: PUL#_PUL#_DIR#_DIR#_EN#_EN#_H#
U$7, U$13, U$39: ESTOP
U$8, U$37: LASER
U$9, U$34: TOOLSET
U$10, U$35: PROBE
U$11, U$38: SPINDLE
U$12: RAIL
U$14: RING
U$16: SD_CARD
U$19: USB
U$23: Y1
U$24: Y2
U$25: X
U$28: 5V_SIG_GND
U$30: EXP
U$31: A
U$32: HTTPS###SIENCI#COM#
U$33: 24#48V

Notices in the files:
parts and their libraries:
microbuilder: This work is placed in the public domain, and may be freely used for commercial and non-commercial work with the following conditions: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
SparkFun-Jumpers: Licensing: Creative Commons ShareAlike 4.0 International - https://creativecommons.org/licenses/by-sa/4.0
